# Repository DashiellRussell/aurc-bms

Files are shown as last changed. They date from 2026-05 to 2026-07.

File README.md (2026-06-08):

# AURC_BMS

Battery Management System for AURC (Australian Universities Rocket Competition).
Four-channel battery board set feeding two flight computers (FC1, FC2) and two pyro boards.
KiCad 10 project set.

## Layout

```
AURC_BMS/
├── libs/                     ← shared, single source of truth (all three boards point here)
│   ├── BMS.kicad_sym         ← symbols
│   ├── BMS.pretty/           ← footprints
│   └── 3dmodels/             ← .step / .wrl
├── docs/
│   ├── interconnect.md                ← the connector contract — READ THIS before touching a board edge
│   ├── architecture.md                ← full design rationale (living doc, currently v0.3)
│   └── board1_power_capture_plan.md   ← Board 1 schematic capture plan (sheets, netlist, BOM)
├── board1_power/             ← Board 1: USB-C, PD sink, 4× SY6970 smart charger, cells, ESP+I²C mux
├── board2_monitor/           ← Board 2: 64-LED gauge + driver, 4× pull-pin power-enable (spine)
├── board3_dist/              ← Board 3: passive fan-out to FC1+Pyro1 / FC2+Pyro2
└── _archive/                 ← previous single-board attempt (v0.1), kept for reference
```

Each `boardN_*/` is an independent KiCad project (`.kicad_pro` / `.kicad_sch` / `.kicad_pcb`) with
its own `sym-lib-table` + `fp-lib-table` that resolve the **shared** library at `../libs/` under
the nickname **`BMS`**. Add a part once in `libs/`; all three boards see it.

## Working on it

- **Before changing any board-to-board connector, edit `docs/interconnect.md` first.** It is the
  only thing keeping the three separately-laid-out boards mate-compatible.
- Add/edit symbols in `libs/BMS.kicad_sym`, footprints in `libs/BMS.pretty/`, 3D models in
  `libs/3dmodels/`. Don't make per-board copies — that defeats the single-source-of-truth setup.
- Open a board by opening its `boardN_*/boardN_*.kicad_pro`.

See `docs/architecture.md` for the full design (protection stack, charging, monitoring,
power-enable/safety, BOM, open items).

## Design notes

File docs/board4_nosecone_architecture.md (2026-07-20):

# AURC Nosecone BMS (board4) — Architecture & Design

**Version:** 0.1
**Scope:** Two-channel, single-board battery board feeding two FC/logic loads in the nosecone.
**Parent design:** `architecture.md` v0.5 (the 4-channel board1–3 set). This board inherits every
decision from that document unless a section below explicitly overrides it. Read that for *why*;
read this for *what changed*.
**Status:** Pre-schematic. Open items in §9.

---

## 1. What this board is

The nosecone carries its own avionics, powered by **two independent 1S 18650 channels**, both
feeding **flight-computer / logic loads** (no pyro). Unlike the main bay's 3-board stack, nosecone
volume dictates a **single PCB**: charger, cells, protection, pull-pin power-enable, monitoring,
and load distribution all on `board4_nosecone`. Rectangular sled mount (dimensions TBD, §9.1).

**Deltas from the 4-channel set, at a glance:**

| | board1–3 set | board4 nosecone |
|---|---|---|
| Channels | 4 (FC1, FC2, Pyro1, Pyro2) | **2 (NFC1, NFC2 — both FC/logic)** |
| Boards | 3-board mezzanine stack | **single board** |
| Pyro path | low-Rds FETs, firing-pulse PTC sizing | **none — no firing pulses anywhere** |
| I²C to chargers | TCA9548A mux (4× SY6970 @ 0x6B) | **no mux — one SY6970 per ESP32-S3 I²C controller** |
| Gauge | Board-2 64-LED IS31FL3731 matrix | **dropped — SK6812 RGB + /STAT LEDs only** |
| WAKE button | on Board 2, via J1s | **on-board tactile switch** |
| PD request | 12 V (30 W budget) | **9 V default (≈15 W budget), 12 V strap option** |

---

## 2. Channel model

- **Two electrically independent 1S channels**: `NCH1_V` → NFC1, `NCH2_V` → NFC2. Independent
  positive rails; returns star-bonded at **one point on this board, next to the cells** (per-channel
  ground-to-star `0Ω` links, R 0603 — same convention as §12 of the parent doc).
- No series stack → no balancing. No pyro → **no low-Rds exception, no firing-pulse arithmetic** —
  the DW01A + SI4920DY stack and PTC are sized purely for FC continuous draw + inrush (§9.2).
- Net names: `NCH{1,2}_V`, `NCH{1,2}_V_SW` (downstream of pull pin), `NCH{1,2}_GND`. The `N` prefix
  keeps nosecone nets grep-distinct from the main set's `CH{1..4}_*`.

## 3. Per-cell protection stack (per channel, cell outward)

Identical philosophy and parts to parent §4, minus the pyro clauses:

1. **Reverse-polarity P-FET at the cell terminal** — DMG2305UX (or AO3401A as drawn in `BMS` lib),
   SOT-23. Keyed holder remains the primary defense; compensate Rds drop via the I²C VREG trim.
2. **DW01A + SI4920DY** in the cell-negative path (`Battery_Management:DW01A`, `BMS:SI4920DY`) —
   over-charge/over-discharge/OC. No lower-Rds substitution needed.
3. **SY6970** power-path charger — same silicon rules as parent §5 (VSYSMIN 3.5 V, BATFET default-on,
   **no ship mode in flight**, `/QON` strapped high). Cap set per parent: bootstrap **47 nF (C 0603)**,
   PMID **6.8 µF (C 0805)**, BAT ≥10 µF (C 0805), SYS ≥10 µF (C 0805), REGN 4.7 µF (C 0603),
   inductor SRP5030CA-2R2M 2.2 µH.
4. **`SYS` / `LOAD_P` source-select 0Ω strap (R 0603)** then **resettable PTC** on each `NCHn_V`
   output. PTC hold/trip sized to the actual nosecone FC draw — **open item §9.2** (no 2 A pulse to
   pass this time, so it can trip much lower than the main board's).

NTC on each SY6970 TS pin (10 k NTC 0603 + bias per datasheet) for the 0–45 °C charge window.

## 4. Charging & USB-C

Parent §5 applies wholesale (single dual-purpose USB-C: PD sink + ESP native USB, USBLC6-2SC6 ESD,
CH224K strap-select). Changes:

- **Budget:** 2 cells × 1.5 A ≈ 12.6 W at the cells ≈ 15 W input → **request 9 V** (a 9 V/2 A phone
  brick suffices); keep the 12 V strap position for sharing the main board's brick.
- Charge current still I²C-programmed (~1.0–1.5 A/cell); ILIM resistor per datasheet.

## 5. I²C topology — mux deleted

Both SY6970s are fixed at 0x6B, but the **ESP32-S3 has two hardware I²C controllers** — so instead
of a TCA9548A:

- **I2C0:** SDA0/SCL0 → SY6970 #1 (NCH1)
- **I2C1:** SDA1/SCL1 → SY6970 #2 (NCH2)
- 4.7 k pull-ups (R 0603) on **each** bus, to the ESP 3V3 rail.

Nothing else shares the buses (no gauge driver on this board). Two parts and a RST line deleted
relative to board1.

## 6. ESP, monitoring & indicators

**ESP32-S3-WROOM-1** on NCH1, same power-gating as parent §7 (as-built board1 scheme):
`NCH1_V → AP2112K-3.3`, EN driven by the MMBD4448HCQW diode-OR of {USB divider, always-on 100 k
strap (R 0603), WAKE, self-hold GPIO}, 100 k pull-down (R 0603), 2N7002 RBF off-jumper shunt.
BLE stream stays **read-only, forever**.

- **WAKE is now an on-board tactile switch** (`NCH1_V` → WAKE through the button), since there is
  no Board 2. Same debounce/limiting as the board1 J1s arrangement.
- **Hardwired LEDs (always fitted, ESP-independent):** per-channel SY6970 /STAT LED (2×, LED 0603 +
  R 0603), USB-present LED, fault LED — the dumb fallback, as parent §9a.
- **Rich status LEDs — DECIDED: (a) 2× SK6812** (ease of use; everything stays ESP-controlled over
  one GPIO). Options considered for the record:
  - **(a) 2× SK6812 RGB**, daisy-chained on one GPIO (parent §9b scheme). Fewest parts, colour
    encodes state, no charge-*level* bar. VDD from `NCH1_V` (same storage-drain caveat — pull cells
    for storage or gate the rail).
  - **(b) IS31FL3731 charlieplex driver** (I²C 0x74, shares a bus with one charger, no address
    clash) + a small LED bar — e.g. 8 LEDs/cell charge bar + 2 diagnostics, ~20 LEDs of the 144 the
    matrix supports, no per-LED resistors, hardware breathe engine. This is Board 2's gauge scaled
    down and pulled on-board; symbol already in the libs.
  - **(c) Raw ESP-GPIO charlieplexing** — no driver IC, but N(N−1) LEDs costs N GPIOs *and*
    firmware scan timing, and the LEDs die the instant the ESP sleeps. Worst of both; avoid.
  - **Recommendation: (a), plus (b) only if a visible charge-level bar on the sled is genuinely
    wanted** — in the nosecone the board is buried at integration, and BLE already gives exact
    numbers on a phone, which weakens the case for a bar this time.
- SoC-by-voltage over BLE via the two chargers' internal ADCs, exactly as the main board.

## 7. Power-enable & outputs

- **2× pull-pin power-enable on a single 4-position screw terminal block** (1×4, one pin pair per
  channel: positions 1–2 = NCH1 loop, 3–4 = NCH2 loop), both **FC-keyed** — no pyro keying needed
  on this board. Pin inserted = isolated; removed = live (captive pins, parent §8). One block
  instead of the main set's four separate 2-pin terminals; silkscreen the two loops clearly since
  the block itself gives no keying.
- Because the pull-pin switch and distribution are on-board, `NCHn_V → strap/PTC → pull-pin →
  NCHn_V_SW → output connector` is one board's routing — no interconnect contract needed beyond:

**J1 — nosecone loads (4-pin, 3 A/pin):**

| Pin | Net |
|---|---|
| 1 | NFC1_V (= NCH1_V_SW) |
| 2 | NFC1_GND (= NCH1_GND) |
| 3 | NFC2_V (= NCH2_V_SW) |
| 4 | NFC2_GND (= NCH2_GND) |

Per-channel V and GND kept separate end-to-end; grounds meet only at the on-board star point.

## 8. BOM deltas vs parent §11

All quantities ×2 instead of ×4 (SY6970QCC, SRP5030CA-2R2M, DW01A+SI4920DY, reverse P-FET, PTC,
NTC, SK6812). Passives R/C **0603** throughout unless a section above says otherwise.

| Change | Part |
|---|---|
| **Deleted** | TCA9548A mux; IS31FL3731 + 64-LED matrix; mezzanine connectors; gauge-button wiring across J1s |
| **Added** | on-board tactile WAKE switch (6×6 mm THT or SMD tact); 1×4 screw terminal block (pull-pin loops, replaces 4× 2-pin terminals) |
| Unchanged | CH224K, ESP32-S3-WROOM-1, AP2112K-3.3, USBLC6-2SC6, MMBD4448HCQW, 2N7002 |

## 9. Open items

1. **Sled dimensions + mounting-hole pattern** — outline TBD; design proceeds electrically first.
2. **Nosecone FC current draw** → PTC hold/trip rating and DW01A OC sanity check.
3. **What exactly are the two loads?** (Two redundant FCs? FC + tracker?) — affects nothing
   electrical so far, but name the connector pins properly once known.
4. **18650 holder orientation on the sled** — axial G-loading on holders; confirm retention.
5. Confirm nosecone is RF-transparent for BLE (fibreglass tip likely fine; carbon is not).
6. **Rich status-LED scheme** — SK6812 vs on-board IS31FL3731 charlieplex bar (§6). Recommendation
   is SK6812-only; decide before capture since it changes the I²C bus loading and LED area.

## 10. Revision history

| Version | Notes |
|---|---|
| 0.1 | Initial: 2-channel FC/logic-only derivative of architecture.md v0.5 on a single sled-mounted board. Mux dropped (dual ESP I²C buses), gauge dropped (SK6812 + /STAT only), WAKE button moved on-board, PD request 9 V default. |

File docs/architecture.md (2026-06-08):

# AURC Avionics BMS — Architecture & Design

**Version:** 0.3 (parts re-confirmed against existing capture; Board 1 plan in `board1_power_capture_plan.md`)
**Scope:** Four-channel battery board set feeding two flight computers (FC1 primary, FC2 backup) and two pyrotechnic boards, for AURC.
**Status:** Board 1 schematic capture in progress. Remaining open items in §13.

> **v0.3 change (2026-06-08):** charger/monitoring topology switched from *MP2617 + MAX17048* to the
> **SY6970** smart charger already drawn in the existing capture. The SY6970 (BQ25896-class) does
> power-path charging **and** integrated I²C V/I/charge monitoring in one IC, so the separate
> MAX17048 fuel gauge is dropped. The TCA9548A mux stays (4× SY6970 share addr 0x6B). ESP confirmed
> as **ESP32-S3-WROOM-1**. Tradeoff: ADC-grade monitoring instead of true coulomb-counting SoC —
> accepted for the lower part count. See §5, §6, §11.

---

## 1. Design philosophy

- **Four electrically independent 1S channels.** One 18650 per channel: FC1, FC2, Pyro1, Pyro2. Independent positive rails; returns joined at a single star point. No series stack → **no cell balancing**.
- **The monitoring layer is non-flight-critical.** The ESP, LED gauge, and BLE telemetry sit entirely outside the flight power path. Fallback is always "fit a charged cell and fly." Nothing in the flight or deployment path may depend on the ESP — hard rule.
- **No on-board arming, no pyro circuitry.** This board does not arm or fire anything. The pull pins are per-channel **power-enable / battery isolation** only. All pyro firing (e-match, firing FET, opto, continuity) lives on the pyro boards downstream; the BMS only delivers power to their inputs.
- **Remove-before-flight power enable.** Pull pin inserted = channel isolated (safe to handle). Pull pin removed = channel power flows.
- **Three boards.** Board 1 (power/charge) and Board 2 (monitor) are active; Board 3 (distribution) is passive.

---

## 2. System architecture

| Board | Role | Key contents |
|---|---|---|
| 1 — Power & charge | active | USB-C (charge + ESP programming), PD sink, 4× SY6970 smart chargers (charge + integrated I²C monitoring), 4× 18650 holders, per-cell protection, I2C mux, ESP module, indicator LEDs |
| 2 — Safe & monitor | active | 64-LED gauge + IS31FL3731 driver, gauge button; pull-pin power-enable interface at the 2→3 edge |
| 3 — Distribution | passive | fan-out to FC1+Pyro1 (Conn A) and FC2+Pyro2 (Conn B) |

**Mechanical (to confirm):** Boards 1 and 3 stack parallel; Board 2 is the spine/interconnect carrying the gauge and the pull-pin interface. Board-to-board via **stacking mezzanine connectors**.

**Inter-board connectors**

- **Board 1 ↔ 2:** 8-pin power (4× V + 4× GND, 3 A/pin) + 4-pin signal (I2C to gauge driver, plus channel-live sense + GND).
- **Board 2 ↔ 3:** 8-pin power (4× V + 4× GND, 3 A/pin) routed through the pull-pin power-enable interface.
- **Board 3 → loads:** Conn A (FC1 V/GND + Pyro1 V/GND), Conn B (FC2 V/GND + Pyro2 V/GND). Per-channel V and GND kept separate.

---

## 3. Channel & independence model

- Four independent positive rails; a fault on one channel cannot pull down another's supply.
- Grounds meet at a **single star point** (location TBD, likely Board 1 by the cells), not a shared plane — independent returns, OZONE PYRO_GND philosophy.
- One USB-C port references the four chargers to a common input ground during charging; acceptable because flight returns are independent and star-bonded at one point. No galvanic isolation.

---

## 4. Per-cell protection stack

In series order from the cell outward:

1. **Reverse-polarity P-FET — at the cell terminal, ahead of the charger tap.** Low-Rds P-FET (DMG2305UX / SI2333-class) so a backwards cell can't reach the SY6970 BAT pin. **Always in circuit, independent of the §5 source select.** It carries full charge + firing-pulse current, so compensate its Rds drop by trimming the I²C charge voltage up by `I_CHG·R_DS`. The **keyed holder is the primary defense**; this FET is the electrical backstop that also guards the charger. *(The SY6970 has its own internal input reverse-blocking FET — 25 mΩ — but that protects the USB side, not against a backwards cell.)*
2. **Protection IC** — DW01A + SI4920DY dual N-FET, in the cell-negative path: over-charge (~4.3 V), over-discharge (~2.4 V), fast electronic over-current/short.
3. **Power-path charger (SY6970)** — switching power-path; see §5. Brings its own layers: **9 A BATFET discharge OCP, 104 % battery OVP, input/system OVP, 160 °C thermal shutdown** (datasheet-verified).
4. **Source select + fuse — on the `CHn_V` output.** A `0Ω` strap picks the channel's output source: **`SYS` (charger power-path, default)** or **`LOAD_P` (direct protected battery)** — see §5/§12. A single resettable **PTC sits after the selector**, fusing the output whichever source is chosen: the slow catastrophic-short backstop for the "silicon failed shorted" case, sized to pass the brief 2 A firing pulse and trip on a sustained short.

**Pyro-channel exception:** the firing-pulse return flows through the DW01A/SI4920DY FETs, so the over-current trip must sit **above** firing inrush. Trip ≈ `V_OV(DW01A ~100–150 mV) ÷ (2·R_DS(SI4920DY))` — verify R_DS keeps this ≳1.5× the 2 A pulse; drop to a lower-Rds FET on the pyro channels if not (§13.4). The pyro cell barely cycles (a few mAh/shot), so over-discharge risk is low.

**Charge temperature cutoff:** NTC on each charger's TS pin to inhibit charging outside ~0–45 °C.

**Over-charge:** doubly covered — DW01A over-charge **and** the SY6970's 104 % VBATOVP.

---

## 5. Charging & USB-C

**Single USB-C port, dual purpose:** PD charging (VBUS + CC) and ESP programming (D+/D- to the S3 module's native USB). Separate pins, no conflict.

- **PD sink** requests 9–12 V (strap-selectable), falls back to 5 V on a non-PD host, so a PC port is never overvolted.
- **4× SY6970 power-path chargers** (Silergy, BQ25896-class), one per cell. ~3.9–14 V input covers both a 5 V PC port and a 9–12 V brick. Switching buck power-path (system/load served first), I²C-programmable input current limit + charge current, TS temperature pin, /STAT + /INT indicators, integrated 16-bit ADC. No external charge-current sense resistor.
- **Switching, not linear** — each charger bucks 12 V → 4.2 V efficiently; no front-end converter needed. Each needs its own inductor (SRP5030CA-2R2M) + input/output caps.
- **Charge current is set over I²C** (CICHG register), not a resistor strap — so it can be tuned in firmware per source. Target ~1.0–1.5 A/cell: 1.0 A fits a 9 V/2 A phone charger (~3 h); 1.5 A (≈0.5 C) wants a 12 V/3 A brick (~2 h). Input-current limit (ILIM pin resistor + I²C DPM) throttles on a weak source.
- **Monitoring comes free:** the same SY6970 reports VBUS/VBAT/VSYS/ICHG/IBUS/TS over I²C — see §6. This is why no separate fuel gauge is fitted.
- **Flight rail = SYS by default.** Each channel's J1 output (`CHn_V`) is picked by a `0Ω` strap: **`SYS`** (charger power-path — default; runs the load from USB while charging, spares the cell) or **`LOAD_P`** (direct protected battery). One PTC after the selector fuses either (§4). Free per-channel choice (e.g. SYS on the FCs, LOAD_P on the pyros) just by which 0Ω is stuffed.
- **Verified SY6970 silicon** (datasheet): VSYSMIN **3.5 V** (3.65 typ), SYS ≈ VBAT+50 mV with a battery present; **BATFET 10 mΩ / 9 A discharge OCP** → a 2 A pyro pulse is trivial; **supplement mode** lets the cell back up the input on load spikes.
- **Reliability rule — never enter ship mode in flight.** BATFET defaults on and the I²C watchdog resets *to* BATFET-on, so SYS survives a dead ESP; but an I²C BATFET-disable (or a 10 s `/QON`-low hold) drops the rail. Strap `/QON` high (no button) and bar firmware from disabling the BATFET on flight channels.
- **Cap corrections** (datasheet typical-app): bootstrap **47 nF** (not 47 µF), **PMID 6.8 µF**, BAT ≥10 µF, SYS ≥10 µF, REGN 4.7 µF.

**ESP programming:** D+/D- straight to the ESP32-S3 module (native USB-Serial-JTAG, no UART bridge). USBLC6-class ESD on D+/D-, BOOT/EN pads. The flight computers are **not** programmed here (their own SWD); the USB bypass only *powers* them for bench debug.

**Power budget:** four cells at 1.5 A ≈ 25 W at the cells ≈ 28 W input, plus ~2 W bypass ≈ 30 W → request 12 V (36 W) for margin.

---

## 6. Sensing & monitoring

- **Monitoring is built into the SY6970 chargers** — each integrates a 16-bit ADC reporting VBAT, VSYS, VBUS, ICHG, IBUS and TS over I²C. No separate fuel gauge or sense resistor is added to the firing path. Tradeoff vs. a dedicated ModelGauge (MAX17048): this is **ADC/voltage-based** state, not true coulomb-counting SoC — accepted for the lower part count; firmware estimates SoC from voltage + charge state + the TS-derived temperature.
- The SY6970 has a **fixed I²C address (0x6B)**, so the four sit behind a **TCA9548A 8-channel I²C mux** (one channel each). Total ESP pins for all monitoring: 2 (SDA/SCL).
- I²C bus topology: ESP → TCA9548A (4× SY6970 chargers, Board 1) and, **upstream of the mux**, across the 4-pin connector → IS31FL3731 gauge driver (Board 2, addr 0x74, no conflict). Pull-ups (4.7 k) on Board 1. The mux RST line (`MUX_RST`) is driven by the ESP.
- Per-cell temperature comes from each SY6970's TS NTC, read back over the same I²C ADC.

---

## 7. ESP, gauge & telemetry

**ESP32-S3-WROOM-1 module** on cell 1 (FC1 channel), behind its own load switch (TPS22917-class) + fuse so a fault can't drag down FC1.
- Reads four SY6970 chargers (V/I/charge/temperature) over the muxed I²C bus.
- Drives the gauge over I2C.
- Streams charge + channel-live state over BLE — **read-only, forever**; never accepts a command.
- Supply regulated to 3.3 V from SYS/charge rail — **never raw VBUS**.

**ESP power gating (as built):** the AP2112K `EN` is driven by a **diode-OR** (`MMBD4448HCQW`, quad common-cathode) of four sources, with a 100 k pull-down → **default off**:
- **USB present** → VBUS 100 k/33 k divider pulls `EN` high (gauge shows charging).
- **Always-on strap** (`R59`, 100 k from `CH1_V`) → sustained-on for flight BLE.
- **Gauge button → `WAKE`** (across the J1↔J2 signal connector, §interconnect) → momentary wake; the ESP then drives its **self-hold** GPIO into the diode-OR to latch on, paints the gauge N s, then releases → powers down.
- **ESP self-hold** GPIO → holds itself on; the **watchdog** drops it on a firmware hang (can't strand it on).
- **Off header (RBF jumper)** — a `2N7002` **shunt** on `EN` (drain→EN, source→GND), gate fed from `CH1_V` through the launch-day jumper `J4`: **jumper in → `EN`→GND → ESP off** (integration/storage week); **removed on launch day → ESP on**. Overrides all four sources (which are current-limited).
- Supply: `CH1_V → AP2112K → 3.3 V`; **never raw VBUS** (VBUS only reaches `EN` through the divider).

*(This replaces the earlier "dedicated TPS22917 load switch" plan — the AP2112K `EN` is the gate; a load switch was deemed redundant for gating only the ESP rail.)*

**Gauge:** 64 LEDs via **IS31FL3731 (eTQFP-28)**, per-LED PWM, hardware breathe/animation engine. Per channel: a charge-level bar plus **2 diagnostic LEDs** (over-temp warning, fault/protection-tripped). Charlieplex matrix — wire the four channels as contiguous blocks. No per-LED resistors. Powered from the charge rail (dead in flight). AD strap = 0x74, SDB to enable/GPIO.

---

## 8. Power-enable (pull pins) & safety

- **Remove-before-flight power enable.** Pin inserted = channel isolated; removed = power flows. *Default-unpinned is live* — use captive/retained pins.
- **Four independent pull pins**, one per channel (4× 2-pin screw terminal), enabling sequenced power-up: bring up FC channels first for checks, pyro channels last.
- **Key/colour the pyro pins** distinctly from the FC pins.
- **Firing-FET-held-off** is a downstream pyro-board requirement, out of BMS scope — but the BMS must deliver clean, transient-free power so applying power can't glitch a load.
- **Hot-plug inrush:** size input caps + soft-start.

---

## 9. Indicator LEDs

Two tiers, so the board is never silent regardless of ESP firmware state.

**9a. Hardwired (ESP-independent) — the dumb fallback**
- Per-channel charge status (4×) from each SY6970 /STAT pin (on = charging, off = done, blink = fault).
- USB / input-present.
- Fault (e.g., protection or charger fault).

These give basic board state even with the ESP off or firmware dead.

**9b. Per-cell RGB status (ESP-driven) — the rich indicator**
- **One addressable RGB LED per cell (SK6812 / WS2812B), 4× total, daisy-chained on a single ESP
  GPIO** (DIN→DOUT through all four). The ESP already reads each SY6970's V/I/charge/fault/temp over
  I²C, so it has everything needed to paint exact per-cell state — visible on Board 1 alone, **no
  Board 2 required**. Because USB-present ⇒ ESP-on, these are live whenever anything is charging.
- Colour scheme (mirrors the Board-2 gauge diagnostics): **green breathing = charging · solid blue =
  charged · red = fault/protection · amber = over-temp · off = idle/no cell.**
- **LED VDD is on `CH1_V`** (the always-live cell rail, *not* the 3V3 LDO) — **note:** ungated, so the SK6812 idle (~2–4 mA total) drains cell 1 during a cells-in storage week; gate the LED rail (or store cells out) if that matters. Original sizing note: (4× WS2812 ≈ 240 mA at full white;
  the AP2112K can't source that). Only the data line touches the ESP — level-shift it (use SK6812
  for 3.3 V tolerance, or a 74AHCT125 / SN74LVC2T45). Dead in flight, like all monitoring.

---

## 10. Operational states

| State | USB | FC pins | Pyro pins | ESP / BLE | Gauge | Loads |
|---|---|---|---|---|---|---|
| Storage (days out) | out | in (isolated) | in (isolated) | off — jumper in | off | off |
| Charging | in | in | in | on, charge rail | levels | off |
| Bench / FC debug | in | out | in | on / momentary | readout | FCs live, pyro isolated |
| Pad power-up | out | out | out (last) | on, BLE — jumper out | off | live |
| Flight / recovery | out | out | out | sleeps on link loss | off | live |

Invariants: chargers inherently dead without USB; per-cell protection always live (µA); gauge never auto-powers off the cells; ESP rail hard-cut by a load switch.

---

## 11. Candidate BOM (verify current LCSC stock + package)

| Function | Candidate | Notes |
|---|---|---|
| Charger + monitor ×4 | **SY6970QCC** | BQ25896-class, ~3.9–14 V in, switching power-path, I²C 0x6B, integrated ADC (V/I/charge/TS), /STAT + /INT. Replaces the MP2617 **and** the fuel gauge. In `libs/BMS.kicad_sym`. |
| Charger inductor ×4 | SRP5030CA-2R2M | 2.2 µH, for the SY6970 buck. In `libs/BMS.kicad_sym`. |
| Protection ×4 | DW01A + SI4920DY dual N-FET | `Battery_Management:DW01A` + `libs/BMS:SI4920DY`. Use a lower-Rds FET on the pyro channels. |
| Reverse-polarity ×4 | AO3401A P-FET (existing) — consider DMG2305UX / SI2333 for lower Rds | `Transistor_FET:AO3401A` |
| Fuse/PTC ×4 | resettable PTC | rated above firing pulse, below sustained short |
| ~~Fuel gauge~~ | **dropped** | monitoring folded into the SY6970 (see §6) |
| I2C mux | TCA9548A | `Interface_Expansion:TCA9548APWR`; hosts the four 0x6B SY6970s |
| PD sink | CH224K (or STUSB4500) | resistor-strap voltage select. In `libs/BMS.kicad_sym`. |
| Gauge driver (Board 2) | IS31FL3731 | eTQFP-28, I²C 0x74, 64 LEDs |
| ESP | ESP32-S3-WROOM-1 | `RF_Module:ESP32-S3-WROOM-1` |
| ESP load switch | TPS22917-class | `Power_Switch` — hard-gates the ESP rail |
| Per-cell RGB status ×4 | SK6812 / WS2812B | addressable, daisy-chained on 1 ESP GPIO; VDD from SYS rail (§9b) |
| LED data level shift | SK6812 (3.3 V tolerant) or 74AHCT125 / SN74LVC2T45 | only if WS2812B used |
| 3V3 LDO | AP2112K-3.3 | `Regulator_Linear:AP2112K-3.3` |
| ESD | USBLC6-2SC6 | `Power_Protection:USBLC6-2SC6`, on D+/D- |

---

## 12. Configuration straps (0Ω / populate)

ESP source select (charge-rail vs cell-1) + always-on capability strap · PD voltage request (9/12/15 V) · ~~per-cell charge-current set~~ *(now I²C-programmed on the SY6970 — only the ILIM input-current resistor remains)* · D+/D- series 0Ω · PD-sink bypass (force 5 V) · per-channel ground-to-star 0Ω · per-channel enable source (pin vs always-on for bench) · **per-channel `CHn_V` source select — `0R_SYS` (default) vs `0R_LOAD`** (SYS power-path vs direct battery, §4/§5).

---

## 13. Open items

1. **Mechanical stack confirmation** — Boards 1 & 3 parallel, Board 2 spine, mezzanine connectors? Confirm mezzanine part/pitch.
2. **Channel-live sense granularity** — combined (1 line, keeps the 4-pin connector) vs per-channel (4 lines, larger connector or local read on Board 2). Needed if the gauge/BLE should show each channel.
3. **Star-point location** — fix it in copper.
4. **Pyro OC trip numbers** — verify firing inrush vs the chosen FS8205 Rds and the PTC rating against the specific e-match.
5. **Project name.**

---

## 14. Revision history

| Version | Notes |
|---|---|
| 0.1 | Initial architecture: 3-board set, 4 independent 1S channels, RBF pull pins, power-path PD charging, dual-purpose USB-C, per-cell protection, non-flight-critical monitoring layer. |
| 0.2 | Parts selected (MP2617 charger, MAX17048 + TCA9548A mux, CH224K PD sink, DW01A+FS8205 protection, IS31FL3731 gauge, ESP32-S3-WROOM-1, P30B 18650 cell). Corrected terminology: no on-board arming — pull pins are power-enable/isolation. Added fuel-gauge sensing, hardwired indicator LEDs, mechanical stack note (Boards 1+3 stacked, Board 2 spine), candidate BOM. |
| 0.3 | **Charger/monitoring topology revised to match existing capture:** SY6970 smart charger (charge + integrated I²C monitoring) replaces MP2617 + MAX17048; separate fuel gauge dropped; TCA9548A mux retained (4× shared 0x6B). ESP confirmed ESP32-S3-WROOM-1. BOM rows mapped to concrete KiCad/`BMS` symbol libraries. Added ESP load-switch (TPS22917) + 3V3 LDO (AP2112K) to BOM. Charge current moved from resistor strap to I²C register. Board 1 capture plan written (`board1_power_capture_plan.md`). Added **per-cell addressable RGB status LEDs** (§9b) on Board 1 — ESP-driven, standalone of Board 2. |
| 0.4 | **Channel output finalized.** Per-channel `CHn_V` is source-selectable by 0Ω — **SYS (default)** or LOAD_P (direct battery); one PTC relocated *after* the selector to fuse either. **Reverse-polarity P-FET moved to the cell terminal** (always-on, now actually guards the charger; Rds drop compensated via I²C VREG); old Q2/Q3 LOAD-branch FETs dropped, keyed holder = primary reverse defense. SY6970 datasheet-verified (VSYSMIN 3.5 V, BATFET 10 mΩ / 9 A OCP, 104 % OVP, supplement mode). Bootstrap cap corrected 47 µF→47 nF, PMID→6.8 µF. Added "no ship-mode in flight" reliability rule. |
| 0.5 | **Board 1 schematic complete (as-built sync).** ESP gate = diode-OR (`MMBD4448HCQW`) of {USB-divider, `CH1_V` always-on strap, `WAKE`, self-hold} → AP2112K `EN`, 100 k pull-down, `2N7002` off-header shunt (RBF: jumper in = off, out = on) — *replaces the TPS22917 load-switch plan*. `CH_LIVE` repurposed to **`WAKE`** on the J1s signal connector (channel-live now derived in firmware via SY6970 I²C / BLE). Board-2 gauge powered from `CH1_V` via the 8-pin power connector (no 3V3 pass-through). All footprints assigned (R/C 0603). Pyro OC-trip verified safe (DW01A ~10 ms delay ≫ <5 ms firing pulse). |

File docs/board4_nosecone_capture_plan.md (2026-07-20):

# Board 4 — Nosecone BMS — Schematic Capture Plan

Capture plan for `board4_nosecone/board4_nosecone.kicad_sch`. Authority order:
`board4_nosecone_architecture.md` (this board's deltas) → `architecture.md` v0.5 (inherited design)
→ this file (capture detail). Where this plan and board1's plan disagree, follow this one —
board1's plan (`board1_power_capture_plan.md`) predates the as-built v0.5 ESP gating.

**Locked decisions (2026-07-20):** single board · 2× FC/logic channels (no pyro) · 2× SY6970, one
per ESP32-S3 I²C controller (**no TCA9548A**) · **2× SK6812** ESP-driven status RGBs + hardwired
/STAT-fallback LEDs (**no IS31FL3731**) · on-board WAKE tact switch · 1×4 screw terminal for both
pull-pin loops · PD request 9 V default · rectangular sled (dims TBD).

> **Head start (already done):** `charge_chanel.kicad_sch` and `USB_IN.kicad_sch` are **copied from
> board1 as-built** into `board4_nosecone/` — both proven sheets, lib refs identical (`BMS:` via the
> project lib tables). The ESP/monitor section is the only fresh drawing, and it's *simpler* than
> board1's (mux deleted).

---

## 1. Sheet hierarchy

```
board4_nosecone.kicad_sch  (ROOT — ESP section drawn here, board1-style)
├── USB_IN.kicad_sch          ×1   USB-C + CH224K + ESD    ← copied, edit strap only
└── charge_chanel.kicad_sch   ×2   SY6970 + protection + 18650 + SK6812   ← copied, use as-is
ROOT also holds: ESP32-S3 + AP2112K + diode-OR gate, WAKE button, J1 out, 1×4 pull-pin block,
star ground, hardwired LEDs.
```

Instantiate **one** `charge_chanel` sheet file twice (NCH1, NCH2). Differences are wired at root
via sheet pins, exactly like board1.

## 2. Global nets (N-prefixed per architecture §2)

| Net | Meaning |
|---|---|
| `VBUS` | PD rail (**9 V** default) |
| `NCH1_V`, `NCH2_V` | per-channel SYS rail (charger out, post-strap/PTC) |
| `NCH1_V_SW`, `NCH2_V_SW` | downstream of pull-pin loop → J1 |
| `NCH1_GND`, `NCH2_GND` | independent returns → single on-board star by the cells |
| `SDA0/SCL0`, `SDA1/SCL1` | ESP I2C0 → SY6970 #1, I2C1 → SY6970 #2 (4.7 k pull-ups to `+3V3` on **each** bus, R 0603) |
| `USB_DP/USB_DM` | native USB to the S3 |
| `+3V3` | AP2112K output |
| `WAKE` | tact switch: `NCH1_V` → button → diode-OR input |
| `STAT1/STAT2` | /STAT → hardwired fallback LEDs |
| `RGB_DATA` → DIN/DOUT chain | 2× SK6812, `LED_VDD` = `NCH1_V` |

## 3. Per-sheet work

**`USB_IN` (copied):** only change — **CH224K strapped to 9 V**. Per datasheet, 9 V = CFG1 = CFG2 =
CFG3 all LOW (GND). As copied from board1: CFG1 already has a 24 K to GND (= logic 0, good), but
**CFG2 and CFG3 are floating** — add a **0 Ω (`R_0603_1608Metric`) from each of CFG2 and CFG3 to
GND**. No 12 V DNP position kept: CFG2/CFG3 cap at 3.7 V so a clean 12 V strap (CFG3 = 1) needs a
≤3.7 V pull-up rail — treat 12 V as a rework if ever needed. Everything else (USBLC6, bulk cap,
input LED) stays.

**`charge_chanel` ×2 (copied):** use as-is. The copied sheet already carries SY6970 + DW01A +
SI4920DY + AO3401A + SRP5030 + PTC + NTC + /STAT + SK6812 with the right cap set (47 nF bootstrap,
6.8 µF PMID, etc.). Per-instance wiring at root: instance 1 gets `SDA0/SCL0`, instance 2 gets
`SDA1/SCL1`. **PTC value may change** vs board1 (no firing pulse — size to FC draw, open item).

**ROOT / ESP section (fresh, ~board1's root minus the mux):**
- `NCH1_V → AP2112K-3.3 → +3V3`. EN = diode-OR (`MMBD4448HCQW`) of {VBUS 100k/33k divider,
  always-on 100 k strap from `NCH1_V`, `WAKE`, ESP self-hold GPIO}, 100 k pull-down, `2N7002`
  RBF-jumper shunt on EN (jumper in = ESP off). All R 0603. Copy this block from board1's root —
  it is the as-built v0.5 circuit.
- ESP32-S3-WROOM-1: `USB_D±` ← `USB_DP/DM`; **two GPIO pairs → `SDA0/SCL0` and `SDA1/SCL1`**
  (any GPIOs — the S3's two I²C controllers route via the GPIO matrix); one GPIO → `RGB_DATA`
  (330 Ω series, R 0603); one GPIO → self-hold into the diode-OR; EN RC + BOOT pad per board1.
- **WAKE tact switch** (6×6 mm): `NCH1_V` → switch → `WAKE` net (through the same limiting as
  board1's J1s arrangement).
- **Firmware note:** advertise as a distinct BLE name (`AURC-BMS-NOSE` vs the main board's
  `AURC-BMS-MAIN`) so the Web Bluetooth page can tell the two boards apart. No RF coexistence
  concern — BLE AFH handles two radios 50 cm apart trivially.

**ROOT / power-out section:**
- Each `NCHn_V` → **1×4 screw terminal** (pull-pin loop: pins 1–2 = NCH1, 3–4 = NCH2) → `NCHn_V_SW`.
- **J1 — loads, 4-pin, 3 A/pin:** 1 `NFC1_V`(=NCH1_V_SW) · 2 `NFC1_GND` · 3 `NFC2_V`(=NCH2_V_SW) ·
  4 `NFC2_GND`.
- **Star ground by the cells:** `NCH1_GND` + `NCH2_GND` + USB GND + signal ground join at exactly
  one node via per-channel 0Ω links (R 0603). No shared plane across channels.

## 4. Config straps (0Ω / DNP, all R 0603)

PD voltage 9 V (default) / 12 V · PD bypass (force 5 V) · D+/D− series 0Ω ×2 · ESP always-on strap ·
per-channel `SYS` vs `LOAD_P` source select ×2 · per-channel ground-to-star ×2 · SY6970 ILIM ×2.

## 5. ERC / verification checklist

- [ ] Both `NCHn_V_SW` reach J1; both `NCHn_GND` reach the star then J1; exactly **one** star node.
- [ ] I2C0 → charger 1 only, I2C1 → charger 2 only; 4.7 k pull-ups once per bus, to `+3V3`.
- [ ] ESP rail from `NCH1_V` via AP2112K — never raw VBUS; diode-OR + 2N7002 shunt per v0.5.
- [ ] Each SY6970: TS NTC, ILIM, REGN/PMID/BAT/SYS caps, inductor; `/QON` strapped high.
- [ ] RGB chain: `RGB_DATA` → NCH1 DIN, NCH1 DOUT → NCH2 DIN; `LED_VDD` = `NCH1_V`; /STAT LEDs kept.
- [ ] Pull-pin block: loop in the **positive** path, `_SW` naming downstream, silkscreen labels.
- [ ] CFG strap = 9 V default; ERC clean, PWR_FLAGs placed; footprints assigned (R/C 0603).

## 6. Capture order

1. Open the copied `USB_IN`, retarget the CFG strap to 9 V.
2. ROOT: instantiate `USB_IN` + one `charge_chanel`, wire `VBUS` + `NCH1_V`, ERC.
3. ROOT: draw the ESP block (copy board1 root's as-built diode-OR/AP2112K section, delete the
   TCA9548A, wire the two I²C pairs) + WAKE switch.
4. Add the second `charge_chanel` instance, pull-pin block, J1, star ground, LEDs, straps.
5. Full ERC vs §5 → annotate → footprints → layout (outline waits on sled dims).

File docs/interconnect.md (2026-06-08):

# AURC BMS — Interconnect Contract

**The single source of truth for everything that crosses a board boundary.**

The BMS is now three separately-laid-out KiCad projects (`board1_power`, `board2_monitor`,
`board3_dist`). Nothing but this document guarantees they mate. Treat every pin map below as
**authoritative**: if a board's connector disagrees with this file, the board is wrong, not the
file. Change a pinout here first, in a commit of its own, before touching copper on either side.

Derived from `architecture_v0.2.md` §2–§3, §6, §8. Read those for *why*; read this for *what pin*.

---

## Channels

Four electrically independent 1S channels. One 18650 each. Independent positive rails; returns
join at a **single star point** (location TBD, §13.3), not a shared plane.

| Channel | Load | Pull-pin colour/key | Notes |
|---|---|---|---|
| CH1 | FC1 (primary flight computer) | FC key | ESP module lives on this channel |
| CH2 | FC2 (backup flight computer) | FC key | |
| CH3 | Pyro1 | PYRO key (distinct) | low-Rds protection FET, carries firing pulse |
| CH4 | Pyro2 | PYRO key (distinct) | low-Rds protection FET, carries firing pulse |

Pin-1 / channel-ordering convention used everywhere below: **CH1 → CH2 → CH3 → CH4** (FC1, FC2,
Pyro1, Pyro2), low pin number first. Keep this order identical on both halves of every connector.

---

## Board stack (mechanical, to confirm — §13.1)

```
        loads (FC1/FC2/Pyro1/Pyro2)
              ▲   ▲
          Conn A   Conn B
              │
   ┌──────────────────────┐
   │  Board 3 — Distribution│  passive fan-out
   └──────────┬─────────────┘
        J3  power 8-pin  (through pull-pin enable interface)
              │
   ┌──────────────────────┐
   │  Board 2 — Safe/Monitor│  spine: 64-LED gauge + 4× pull pins
   └───┬──────────────┬─────┘
   J2 power 8-pin   J2s signal 4-pin
       │              │
   ┌──────────────────────┐
   │  Board 1 — Power/Charge│  USB-C, 4× charger, cells, fuel gauges, ESP
   └──────────────────────┘
```

Boards 1 and 3 stack parallel; Board 2 is the spine carrying the gauge and the pull-pin interface.
Board-to-board via **stacking mezzanine connectors** — part/pitch **TBD (§13.1)**. The pin maps
below are logical; assign physical positions once the mezzanine part is chosen, preserving the
CH1→CH4 ordering and keeping each channel's V adjacent to its own GND.

---

## J1 — Board 1 ↔ Board 2  (power, 8-pin)

4× channel rails + 4× returns. **3 A per pin.** Each channel's V paired adjacent to its own GND
(independent returns — do not common the grounds here).

| Pin | Net | Pin | Net |
|---|---|---|---|
| 1 | CH1_V (FC1) | 2 | CH1_GND |
| 3 | CH2_V (FC2) | 4 | CH2_GND |
| 5 | CH3_V (Pyro1) | 6 | CH3_GND |
| 7 | CH4_V (Pyro2) | 8 | CH4_GND |

Each rail is the per-channel **`CHn_V`** output: a `0Ω` strap selects its source — **`SYS`** (SY6970
power-path, **default**) or **`LOAD_P`** (direct protected battery) — and a single PTC fuses it after
the selector. Live whenever a charged cell is fitted (independent of USB). See architecture §4/§5/§12.

## J1s — Board 1 ↔ Board 2  (signal, 4-pin)

I²C to the Board-2 gauge driver, plus the gauge-button **wake** line.

| Pin | Net | Notes |
|---|---|---|
| 1 | SDA | I²C, pulled up 4.7 k on **Board 1** |
| 2 | SCL | I²C, pulled up 4.7 k on **Board 1** |
| 3 | **WAKE** | Board-2 gauge button → Board-1 ESP enable (momentary; the button connects `CH1_V` → `WAKE`, which feeds the ESP-enable diode-OR) |
| 4 | SGND | signal ground reference |

**Board-2 power:** the gauge (IS31FL3731 + LED matrix) is powered **directly from `CH1_V`** via the 8-pin power connector (J1) — no 3V3 pass-through, no Board-2 regulator. The 3.3 V I²C bus is level-compatible across the cell range; the gauge is dark in flight (ESP off → no I²C frames).

**I²C topology:** ESP → TCA9548A → 4× **SY6970** chargers (each addr 0x6B, integrated V/I/charge/TS
monitoring — no separate fuel gauge), all on Board 1. The IS31FL3731 gauge driver on Board 2
(addr **0x74**, no conflict) sits **upstream of the mux** and is reached across J1s. Only SDA/SCL
cross the boundary; the mux and chargers stay on Board 1. Pull-ups (4.7 k) live on Board 1.

> **RESOLVED (§13.2).** The dedicated channel-live line was **dropped** — pin 3 now carries `WAKE`.
> Channel-live state is derived in firmware from the SY6970 I²C readings and streamed over BLE /
> shown on the gauge, so no hardware sense line is needed. J1s stays 4-pin.

---

## J2 — Board 2 ↔ Board 3  (power, 8-pin, through the pull-pin enable interface)

Same 4× V / 4× GND map as J1, **but routed through the four pull-pin power-enable switches on
Board 2.** Pin inserted = channel isolated (safe); pin removed = power flows (*default-unpinned is
live* — use captive/retained pins, §8).

| Pin | Net | Pin | Net |
|---|---|---|---|
| 1 | CH1_V_SW (FC1) | 2 | CH1_GND |
| 3 | CH2_V_SW (FC2) | 4 | CH2_GND |
| 5 | CH3_V_SW (Pyro1) | 6 | CH3_GND |
| 7 | CH4_V_SW (Pyro2) | 8 | CH4_GND |

`_SW` = downstream of the pull-pin switch. Grounds pass straight through (returns stay independent).
**3 A per pin.** Pull pins themselves are 4× 2-pin screw terminals on Board 2, **not** part of this
connector. Key/colour the two PYRO pins distinctly from the two FC pins.

---

## J3 — Board 3 → loads  (distribution fan-out)

Board 3 is passive. It splits the four switched channels into two load connectors, each carrying a
flight computer **and** its paired pyro board. Per-channel V and GND kept separate end-to-end.

### Conn A — FC1 + Pyro1
| Pin | Net |
|---|---|
| 1 | FC1_V (= CH1_V_SW) |
| 2 | FC1_GND  (= CH1_GND)  |
| 3 | PYRO1_V  (= CH3_V_SW) |
| 4 | PYRO1_GND(= CH3_GND)  |

### Conn B — FC2 + Pyro2
| Pin | Net |
|---|---|
| 1 | FC2_V (= CH2_V_SW) |
| 2 | FC2_GND  (= CH2_GND)  |
| 3 | PYRO2_V  (= CH4_V_SW) |
| 4 | PYRO2_GND(= CH4_GND)  |

The BMS delivers power only — **no arming, no pyro circuitry** on any of these three boards. Firing
FETs, opto-isolation, e-match continuity all live on the downstream pyro boards. The BMS must
deliver clean, transient-free power so applying it can't glitch a load (size input caps + soft-start
on Board 1, §8).

---

## Net-name conventions (use these exact labels on hierarchical pins / global labels)

- `CH{1..4}_V`      — protected, charge-side rail, Board 1 output → J1
- `CH{1..4}_V_SW`   — same rail after the Board-2 pull-pin switch → J2/J3
- `CH{1..4}_GND`    — that channel's independent return (star-bonded at one point only)
- `SDA` / `SCL`     — I²C bus (4.7 k pull-ups on Board 1)
- `WAKE`            — Board-2 gauge button → Board-1 ESP enable (momentary; replaced `CH_LIVE`)
- `SGND`            — signal/I²C reference

Star-point: bond the four `CH*_GND` returns at exactly **one** location (likely Board 1 by the
cells, §13.3) via per-channel ground-to-star 0 Ω links (§12). Nowhere else.

---

## Open items affecting this contract

1. **§13.1** Mezzanine connector part + pitch → fixes physical pin assignment of J1/J1s/J2.
2. ~~**§13.2** Channel-live sense granularity~~ **RESOLVED** — line dropped; pin 3 = `WAKE`, channel-live derived in firmware.
3. **§13.3** Star-point location → which board carries the ground-to-star 0 Ω links.

When any of these closes, edit this file **first**, in its own commit, then update both board edges.

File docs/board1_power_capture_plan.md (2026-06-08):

# Board 1 — Power & Charge — Schematic Capture Plan

Capture plan for `board1_power/board1_power.kicad_sch`. Draw it in KiCad from this; it's the
engineering, not the drawing. Authority order: `interconnect.md` (board edges) → `architecture.md`
(design intent) → this file (Board 1 detail).

**Locked decisions (2026-06-08):** SY6970 smart charger (charge + integrated I²C monitoring, no
separate fuel gauge) · ESP32-S3-WROOM-1 · TCA9548A I²C mux · 4 independent 1S channels (FC1, FC2,
Pyro1, Pyro2) · single star ground on Board 1.

> **Build status (2026-06-08):** the drawn capture was **migrated** from the archived single-board
> design into `board1_power/` — `USB_IN.kicad_sch` and the 4× `charge_chanel.kicad_sch` instances
> are live (lib refs fixed to `BMS:`), validated by `kicad-cli sch erc` (loads clean, 169 WIP
> violations — unconnected pins, no PWR_FLAGs, "Unspecified" pin-type warnings from the imported
> symbols). **Remaining build (do in KiCad GUI, in order):** ① swap ESP32-C3 → ESP32-S3-WROOM-1 ·
> ② add TCA9548A mux + wire each channel's I²C to its mux port (§5 table) · ③ add the 4× RGB chain +
> TPS22917 load switch (§5, §9b) · ④ add J1 / J1s connectors (§6, `interconnect.md`) · ⑤ star
> ground (§7) · ⑥ finish root wiring, add PWR_FLAGs, place the 2nd unit of the dual FET, clear ERC.

> **Pin numbers:** connections below are given **by pin function/name**, because the safe move is
> to confirm physical pin numbers against each part's symbol + datasheet as you place it. For the
> charge channel and USB input you already have a *drawn reference* in
> `_archive/single-board-v0.1/` (`charge_chanel.kicad_sch`, `USB_IN.kicad_sch`) — open it alongside.

---

## 0. What lives on Board 1

USB-C input + PD sink · 4× SY6970 power-path chargers (+ per-cell protection + 18650) · ESP32-S3 +
TCA9548A mux + 3V3 LDO behind a load switch · hardwired indicator LEDs · the two board-edge
connectors **J1** (8-pin power out) and **J1s** (4-pin signal). Star ground is here.

Nothing flight-critical depends on the ESP. The four SYS rails leave via J1 regardless of ESP state.

---

## 1. Sheet hierarchy

```
board1_power.kicad_sch  (ROOT)
├── usb_in.kicad_sch              ×1   USB-C + CH224K PD sink + ESD + input caps
├── charge_channel.kicad_sch      ×4   one per cell — SY6970 + protection + 18650   ← reusable design
└── esp_monitor.kicad_sch         ×1   ESP32-S3 + TCA9548A mux + AP2112K 3V3 + TPS22917 load switch
ROOT also holds: J1, J1s, star-ground node, fault LED, the global rails.
```

Use **one** `charge_channel` sheet file, instantiated 4×. Per-instance differences (which load,
which mux channel, pin colour) are wired at the root via sheet pins — the sheet itself is generic.

**Sheet pins (the contract between each sub-sheet and root):**

| Sheet | In | Out / bidir |
|---|---|---|
| `usb_in` | — | `VBUS` (PD rail, ~12 V), `USB_DP`, `USB_DM`, `GND` |
| `charge_channel` | `VBUS`, `SDA_n`, `SCL_n`, `RGB_DIN`, `LED_VDD`, `GND` | `CHn_V` (= SYS rail), `STATn`, `RGB_DOUT` |
| `esp_monitor` | `VBUS_PRESENT`/`SYS_FC1` (ESP rail source), `SDA`,`SCL` (main bus), `USB_DP`,`USB_DM`, `GND` | `SDA0..3`,`SCL0..3` (mux downstream → the 4 channels), `MUX_RST`, `RGB_DATA` (to first cell's `RGB_DIN`) |

**Per-cell RGB chain:** the ESP's `RGB_DATA` → instance 1's `RGB_DIN`; each instance's `RGB_DOUT` →
the next instance's `RGB_DIN` (daisy chain, one data line for all four). `LED_VDD` is the **SYS/charge
rail**, *not* `+3V3`. See §9b of `architecture.md` for colour semantics.

> `SDA_n`/`SCL_n` on each `charge_channel` instance connect to a **different** mux downstream pair
> (`SDA0/SCL0` → channel 1, … `SDA3/SCL3` → channel 4). That's how four identical 0x6B chargers
> coexist. Keep the channel→mux-port mapping fixed and documented (table in §6).

---

## 2. Global nets / naming (match `interconnect.md`)

| Net | Meaning |
|---|---|
| `VBUS` | PD-negotiated input rail (~12 V) feeding all four chargers + the ESP rail source |
| `CH1_V`..`CH4_V` | each channel's SYS rail (charger output) → J1. **= FC1, FC2, Pyro1, Pyro2** |
| `CH1_GND`..`CH4_GND` | each channel's independent return → star point (§7) → J1 |
| `SDA`,`SCL` | ESP main I²C bus (4.7 k pull-ups on Board 1) |
| `SDA0..3`,`SCL0..3` | mux downstream pairs → the four SY6970s |
| `MUX_RST` | ESP → TCA9548A reset (active low) |
| `USB_DP`,`USB_DM` | USB D+/D- → ESP native USB |
| `+3V3` | ESP/logic rail (LDO output, downstream of load switch) |
| `CH_LIVE` | combined channel-live sense → J1s (see open item §13.2) |
| `STAT1..4` | per-channel /STAT (to hardwired fallback LEDs) |
| `RGB_DATA` → `RGB_DIN/DOUT` chain | per-cell addressable RGB status, daisy-chained (§9b) |
| `LED_VDD` | RGB LED supply = **SYS/charge rail** (not +3V3) |

---

## 3. Sheet `usb_in` — USB-C + PD sink  (reuse archived `USB_IN.kicad_sch` ~as-is)

This already matches v0.3. Components: `Connector:USB_C_Receptacle_USB2.0_16P`, `BMS:CH224K`,
`Power_Protection:USBLC6-2SC6`, input bulk cap (`Device:C_Polarized`), decoupling, status LED.

Connections (by function — confirm pins):

- **USB-C** VBUS pins (A4/A9/B4/B9) → `VBUS_RAW`; GND pins (A1/A12/B1/B12) + shield → `GND`.
- **CC1/CC2** → CH224K CC1/CC2. **D+/D-** → through USBLC6 → `USB_DP`/`USB_DM` (series 0Ω strap each).
- **CH224K**: VBUS in ← `VBUS_RAW`; VOUT/sense → `VBUS`; **CFG/PG resistor strap sets the requested
  voltage** (9/12/15 V — populate per §8); decouple VDD. PG/status → input-present LED (green).
- **USBLC6** across D+/D- and VBUS for ESD; one device covers both data lines + VBUS clamp.
- Input bulk cap on `VBUS` (hot-plug inrush, §8) + soft-start consideration at the board level.

Sheet-pin out: `VBUS`, `USB_DP`, `USB_DM`, `GND`.

> Note: CH224K negotiates *input* voltage. Per-channel charge regulation is the SY6970's job.

---

## 4. Sheet `charge_channel` (×4) — SY6970 + protection + cell

**You already drew this** (archived `charge_chanel.kicad_sch`: SY6970QCC + DW01A + SI4920DY +
AO3401A + SRP5030 + Polyfuse + NTC + STAT LED). Re-draw it into the new project (capture-plan-only),
or open the archive as your template. Target net list per instance:

**Components:** `BMS:SY6970QCC` (U), `Battery_Management:DW01A` (U), `BMS:SI4920DY` dual N-FET (Q),
`Transistor_FET:AO3401A` P-FET (Q, reverse-polarity), `BMS:SRP5030CA-2R2M` 2.2µH (L),
`Device:Polyfuse` PTC (F), `Device:Thermistor_NTC` (RT), `Device:LED` (D, /STAT hardwired fallback),
**SK6812/WS2812B addressable RGB (D, per-cell status — §9b)**, 18650 holder
(`Connector`/`Device:Battery`), input/output caps, ILIM + TS divider + I²C-section resistors.

**Power path (cell → SYS):**
1. **18650** `CELL_P` / `CELL_N`.
2. **Protection (DW01A + SI4920DY)** in the cell-negative line: the two series N-FETs sit between
   `CELL_N` and the channel's protected negative (`B_MINUS`). DW01A: VDD←`CELL_P` (via 100Ω+0.1µF
   RC), GND←`B_MINUS`, CS/Vm← the FET-junction node, OC/OD gates → SI4920DY gates. *(Canonical DW01A
   1S circuit — mirror the archived sheet.)* Over-charge ~4.3 V, over-discharge ~2.4 V, OC trip set
   by FET Rds. **Pyro channels: use the lower-Rds FET option** so the firing pulse doesn't trip OC.
3. **Reverse-polarity P-FET (AO3401A)** in the protected positive line: source→`CELL_P`, drain→
   `VBAT_PROT`, gate→`B_MINUS` via 100k. (Consider DMG2305UX/SI2333 for lower Rds — §11.)
4. **PTC fuse** in series (positive line) — sized above the 2 A firing pulse, below sustained short.
5. **SY6970**: `BAT` ↔ `VBAT_PROT`; `SW` → inductor `L` → ; `SYS` → **`CHn_V`** (sheet-pin out, the
   J1 rail); `VBUS` ← global `VBUS`; `PMID` cap to GND; `REGN` cap; `ILIM` resistor to GND (input
   current limit); `TS` ← NTC divider (charge temp cutoff 0–45 °C); `/STAT` → STAT LED **and**
   sheet-pin `STATn`; `/CE` tie enabled (or ESP GPIO later); `SDA`/`SCL` ← sheet-pins `SDA_n`/`SCL_n`
   (this channel's mux pair); `OTG`/boost unused — tie per datasheet; D+/D- on SY6970 unused (PD is
   handled upstream) — terminate per datasheet.
6. **Decoupling:** VBUS in-cap, SYS out-cap, BAT cap, REGN/PMID caps per SY6970 datasheet.

**Ground:** this channel's return is `CHn_GND` — kept independent, joined only at the star (§7).

**RGB status LED (§9b):** one SK6812/WS2812B per cell. `VDD` ← `LED_VDD` (SYS rail) + 0.1µF;
`DIN` ← sheet-pin `RGB_DIN`; `DOUT` → sheet-pin `RGB_DOUT`; `GND` ← `CHn_GND`. The dumb `/STAT` LED
stays as the firmware-independent fallback.

Sheet-pins: in `VBUS`,`SDA_n`,`SCL_n`,`RGB_DIN`,`LED_VDD`,`GND` · out `CHn_V`,`STATn`,`RGB_DOUT`.

---

## 5. Sheet `esp_monitor` — ESP32-S3 + mux + 3V3 + load switch

**This is the main *new* capture work** (archived top sheet was ESP32-C3 + AP2112K; upgrade to S3
and add the mux + load switch).

**Components:** `RF_Module:ESP32-S3-WROOM-1` (U), `Interface_Expansion:TCA9548APWR` (U),
`Regulator_Linear:AP2112K-3.3` (U), `Power_Switch:TPS22917...` load switch (U), I²C pull-ups,
decoupling, BOOT/EN parts, optional gauge button input.

**ESP rail gating (the hard gate, §7 of architecture):**
- ESP-rail source = charge/SYS rail (strap-select SYS_FC1 vs charge rail — §8), **never raw VBUS**.
- That source → **TPS22917 load switch** (ON pin driven by: USB-present OR gauge-button latch OR
  launch-day jumper — see arch §7 states) → **AP2112K-3.3** → `+3V3` → ESP `3V3` + decoupling.
- TPS22917 is the real gate firmware can't defeat; add a watchdog/timeout downstream.

**ESP32-S3:**
- `3V3` ← `+3V3`; multiple `GND`; `EN` pull-up + RC; `IO0`(BOOT) pull-up + button/pad.
- **Native USB:** `USB_D+`/`USB_D-` ← `USB_DP`/`USB_DM` (programming over USB-Serial-JTAG; no UART
  bridge). USBLC6 ESD is on the usb_in sheet.
- **I²C main bus:** two GPIO → `SDA`/`SCL` (4.7 k pull-ups to +3V3 *here*).
- `MUX_RST` → one GPIO. Optional `/INT` aggregation from chargers → one GPIO.
- **`RGB_DATA` → one GPIO → first cell's `RGB_DIN`** (per-cell RGB chain, §9b). If WS2812B, put a
  level shifter (74AHCT125 / SN74LVC2T45) on this line; SK6812 usually tolerates 3.3 V direct. Add a
  ~330 Ω series resistor at the source and a bulk cap on `LED_VDD`.
- Optional: gauge-button input GPIO; STAT sense GPIOs (telemetry) — non-critical.

**TCA9548A mux:**
- `VCC`←`+3V3`, decouple; `A0/A1/A2` → address straps (pick 0x70); `/RESET`←`MUX_RST`.
- **Upstream** `SDA`/`SCL` ← ESP main bus `SDA`/`SCL`.
- **Downstream** SD0/SC0..SD3/SC3 → `SDA0/SCL0`..`SDA3/SCL3` (sheet-pins to the 4 channels).
- The Board-2 IS31FL3731 (0x74) sits on the **main** bus (upstream of mux) and exits via J1s — it is
  *not* on a mux channel (unique address, no conflict).

**Mux-channel ↔ cell map (fix this and don't change it):**

| Mux ch | Pair | Channel | Load |
|---|---|---|---|
| 0 | SDA0/SCL0 | CH1 | FC1 |
| 1 | SDA1/SCL1 | CH2 | FC2 |
| 2 | SDA2/SCL2 | CH3 | Pyro1 |
| 3 | SDA3/SCL3 | CH4 | Pyro2 |
| 4–7 | — | spare | — |

Sheet-pins: in `ESP_RAIL_SRC`,`SDA`,`SCL`,`USB_DP`,`USB_DM`,`GND` · out `SDA0..3`,`SCL0..3`,`MUX_RST`,`RGB_DATA`.

---

## 6. ROOT sheet — instances, connectors, star ground

- Place the 6 sheet instances (1× usb_in, 4× charge_channel, 1× esp_monitor).
- Wire each `charge_channel` instance's `SDA_n`/`SCL_n` to its mux pair per the table above.
- Bus `VBUS` from usb_in → all four charge_channels + esp_monitor rail source.
- **J1 — power, 8-pin** (`Connector_Generic:Conn_02x04` or chosen mezzanine):
  `CH1_V`/`CH1_GND` … `CH4_V`/`CH4_GND`, pin order = interconnect.md §J1, 3 A/pin.
- **J1s — signal, 4-pin:** `SDA`, `SCL`, `CH_LIVE`, `SGND`.
- **`CH_LIVE`** (combined): derive from a diode-OR of the four SYS rails through a divider to a
  logic-level sense (or revisit §13.2 if per-channel is needed). Mark as provisional.
- **Fault LED** (board-level) + input-present LED (on usb_in).

---

## 7. Star ground (architecture §3)

The four `CHn_GND` returns are **independent** up to a single star node on Board 1 (by the cells).
Join them there with per-channel `0Ω` links (§8 strap) — and reference USB `GND` and signal `SGND`
to that same node. **Nowhere else.** Do not pour one continuous ground plane across all four
channels; keep four return regions meeting at the star. This is the OZONE PYRO_GND philosophy.

---

## 8. Config straps (architecture §12 — place as 0Ω / DNP pads)

- **PD voltage request** (CH224K CFG): 9 / 12 / 15 V — default 12 V.
- **PD-sink bypass** (force 5 V) for a dumb host.
- **D+/D- series 0Ω** (×2) — isolate ESP USB if needed.
- **ESP rail source select** (charge-rail vs cell-1) + **always-on capability** strap.
- **SY6970 ILIM resistor** per channel (input-current limit; charge current itself is I²C-set).
- **Per-channel ground-to-star 0Ω** (×4) — the star links.
- **Per-channel enable source** (`/CE` from pull vs always-on for bench).

---

## 9. Library / symbol map

| Need | Symbol | Source | Status |
|---|---|---|---|
| Charger+monitor | `SY6970QCC` | `libs/BMS.kicad_sym` | ✓ have |
| Inductor 2.2µH | `SRP5030CA-2R2M` | `libs/BMS.kicad_sym` | ✓ have |
| PD sink | `CH224K` | `libs/BMS.kicad_sym` | ✓ have |
| Protection FET | `SI4920DY` | `libs/BMS.kicad_sym` | ✓ have |
| Protection IC | `DW01A` | `Battery_Management` | ✓ stock |
| Rev-polarity P-FET | `AO3401A` (or DMG2305UX) | `Transistor_FET` | ✓ stock (AO3401A) |
| ESP | `ESP32-S3-WROOM-1` | `RF_Module` | ✓ stock |
| I²C mux | `TCA9548APWR` | `Interface_Expansion` | ✓ stock |
| 3V3 LDO | `AP2112K-3.3` | `Regulator_Linear` | ✓ stock |
| Load switch | `TPS22917...` | `Power_Switch` | ✓ stock (pick variant) |
| ESD | `USBLC6-2SC6` | `Power_Protection` | ✓ stock |
| Per-cell RGB ×4 | `SK6812` / `SK6812MINI-E` / `WS2812B` | `LED` | ✓ stock (confirm footprint variant) |
| LED level shifter (opt) | `74AHCT1G125` | `74xGxx` | ✓ stock; only if WS2812B |
| USB-C | `USB_C_Receptacle_USB2.0_16P` | `Connector` | ✓ stock |
| PTC / NTC / R / C / LED | `Device:*` | `Device` | ✓ stock |
| 18650 holder | `Device:Battery` / `Connector` | `Device` | ✓ stock |

**Footprints to confirm before layout:** SY6970 package (QFN — already in `BMS.pretty`?), TCA9548APWR
(TSSOP-24), ESP32-S3-WROOM-1 (RF_Module.pretty), TPS22917 (SOT-23-6), DW01A (SOT-23-6), SI4920DY
(SOIC-8 — in `BMS.pretty`), AO3401A (SOT-23). No new *symbols* need creating — good.

---

## 10. ERC / verification checklist

- [ ] All four `CHn_V` reach J1; all four `CHn_GND` reach the star then J1.
- [ ] Exactly **one** star node; no second ground tie between channels.
- [ ] I²C: 4.7 k pull-ups present once (on +3V3 main bus); each SY6970 on its own mux channel;
      gauge driver (0x74) on main bus, not a mux channel; `MUX_RST` driven.
- [ ] ESP rail comes through the load switch + LDO, **never raw VBUS**; load switch ON logic correct.
- [ ] Each SY6970 has TS NTC, ILIM resistor, REGN/PMID/BAT/SYS caps, inductor on SW.
- [ ] Pyro-channel protection FET is the low-Rds option (won't trip on firing pulse).
- [ ] RGB chain: `RGB_DATA`→cell1 `DIN`, each `DOUT`→next `DIN`; `LED_VDD` = SYS rail (not +3V3);
      series R + level shift present if WS2812B; hardwired `/STAT` LED still present per cell.
- [ ] No power-flag/unconnected ERC errors; every hierarchical sheet pin matches its label.
- [ ] J1 / J1s pinout byte-for-byte matches `interconnect.md`.
- [ ] PD CFG strap set to a sane default (12 V); bypass-to-5V strap present.

---

## 11. Suggested capture order

1. `usb_in` (smallest, reuse archived) → get `VBUS` clean.
2. `charge_channel` ×1 (reuse archived; review against §4) → ERC one channel in isolation.
3. ROOT: instantiate that one channel + usb_in, verify `VBUS` + one `CHn_V`.
4. `esp_monitor` (the new work: S3 + mux + load switch).
5. ROOT: wire mux↔channel I²C, add the other 3 channel instances, J1, J1s, star ground, LEDs.
6. Full ERC pass against §10. Then annotate + assign footprints → ready for layout.

---

## 12. Open items that touch Board 1

- **§13.2** `CH_LIVE` combined vs per-channel → J1s pin count + the root sense circuit.
- **§13.3** Star-point exact location in copper (this plan assumes Board 1 by the cells).
- **§13.4** Pyro OC trip: verify firing inrush vs chosen SI4920DY Rds + PTC rating vs the e-match.
- Confirm SY6970 footprint + LCSC stock; confirm TPS22917 variant (latching vs non-latching ON).

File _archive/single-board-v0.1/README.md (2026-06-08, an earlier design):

# Archived — single-board attempt (v0.1)

This is the original **single-board** AURC_BMS layout, archived on 2026-06-08 when the design was
split into the three-board set (`board1_power`, `board2_monitor`, `board3_dist`) per
`docs/architecture_v0.2.md`.

Kept for reference only — do **not** continue work here.

Contents:
- `AURC_BMS.kicad_pro` / `.kicad_sch` / `.kicad_pcb` — top-level single-board project
- `charge_chanel.kicad_sch`, `USB_IN.kicad_sch` — hierarchical sheets (per-channel charger, USB input)
- `sym-lib-table`, `fp-lib-table` — original project-local lib tables (referenced the
  `easyeda2kicad` library nicknames, since renamed to `BMS` and relocated to `../../libs/`)

The schematics embed their symbol definitions (`lib_symbols`), so they still open and display even
though the library was renamed. Footprint/3D-model links may not resolve against the new `libs/`
layout — expected, since this is frozen reference material.

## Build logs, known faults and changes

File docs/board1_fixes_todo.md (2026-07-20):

# Board 1 (main power board) — outstanding fixes

Found while building board4 (nosecone), which was copied from board1 — these bugs exist on
**board1_power** too and need fixing there. Board1 already has placed copper, so both are a
schematic **and** layout touch.

## 1. PD voltage-select straps incomplete (CFG2/CFG3 floating)

`board1_power/USB_IN.kicad_sch` — the CH224K is **not deterministically set to 12 V**. As drawn:
- CFG1 → 24 K to GND = logic 0 ✅
- **CFG2 → floating** ✗
- **CFG3 → floating** ✗

Floating CFG pins have no reliable internal default (datasheet: "add external pull-up/pull-down to
set CFG2/CFG3"), so the negotiated voltage is undefined — it may sit at 5/9/12 V unpredictably. The
4-cell board needs a real 12 V (≈30 W budget; a 9 V/2 A phone brick can't feed it), so silently
running at 9 V would input-current-limit and charge slow.

**Fix — set 12 V (CFG1=0, CFG2=0, CFG3=1):**
- CFG2 → **0 Ω to GND** (`R_0603_1608Metric`)
- CFG3 → **~10 K pull-up to `VDD_PD`** (the CH224K's own VDD rail, **not** VBUS and **not** +3V3 —
  must be ≤3.7 V; VDD_PD is alive the instant the chip powers, so no timing dependency)

*(For reference, board4/nosecone uses 9 V = all three CFG to GND — simpler, no pull-up needed.)*

## 2. Heartbeat LED has no series resistor

`board1_power` root — the heartbeat LED **D1** is wired ESP `IO2` (pin 38) → D1 → GND with **no
current-limiting resistor**. An LED straight across a 3.3 V GPIO is limited only by the pin's drive
strength (ESP32-S3 ~40 mA abs max) — stresses the GPIO and over-drives the LED.

**Fix:** insert a series resistor, `IO2 → R → D1 anode`, D1 cathode → GND.
- **1 kΩ** recommended (≈1.3 mA, plenty for a status blink, easy on the battery), `R_0603_1608Metric`.
- (This same bug was pasted into board4 and is being fixed there too.)

---

*Both fixes were identified 2026-07-21. Neither blocks the board from powering, but #1 means the
charge voltage is wrong/undefined and #2 stresses a GPIO — do both before the next board1 revision.*

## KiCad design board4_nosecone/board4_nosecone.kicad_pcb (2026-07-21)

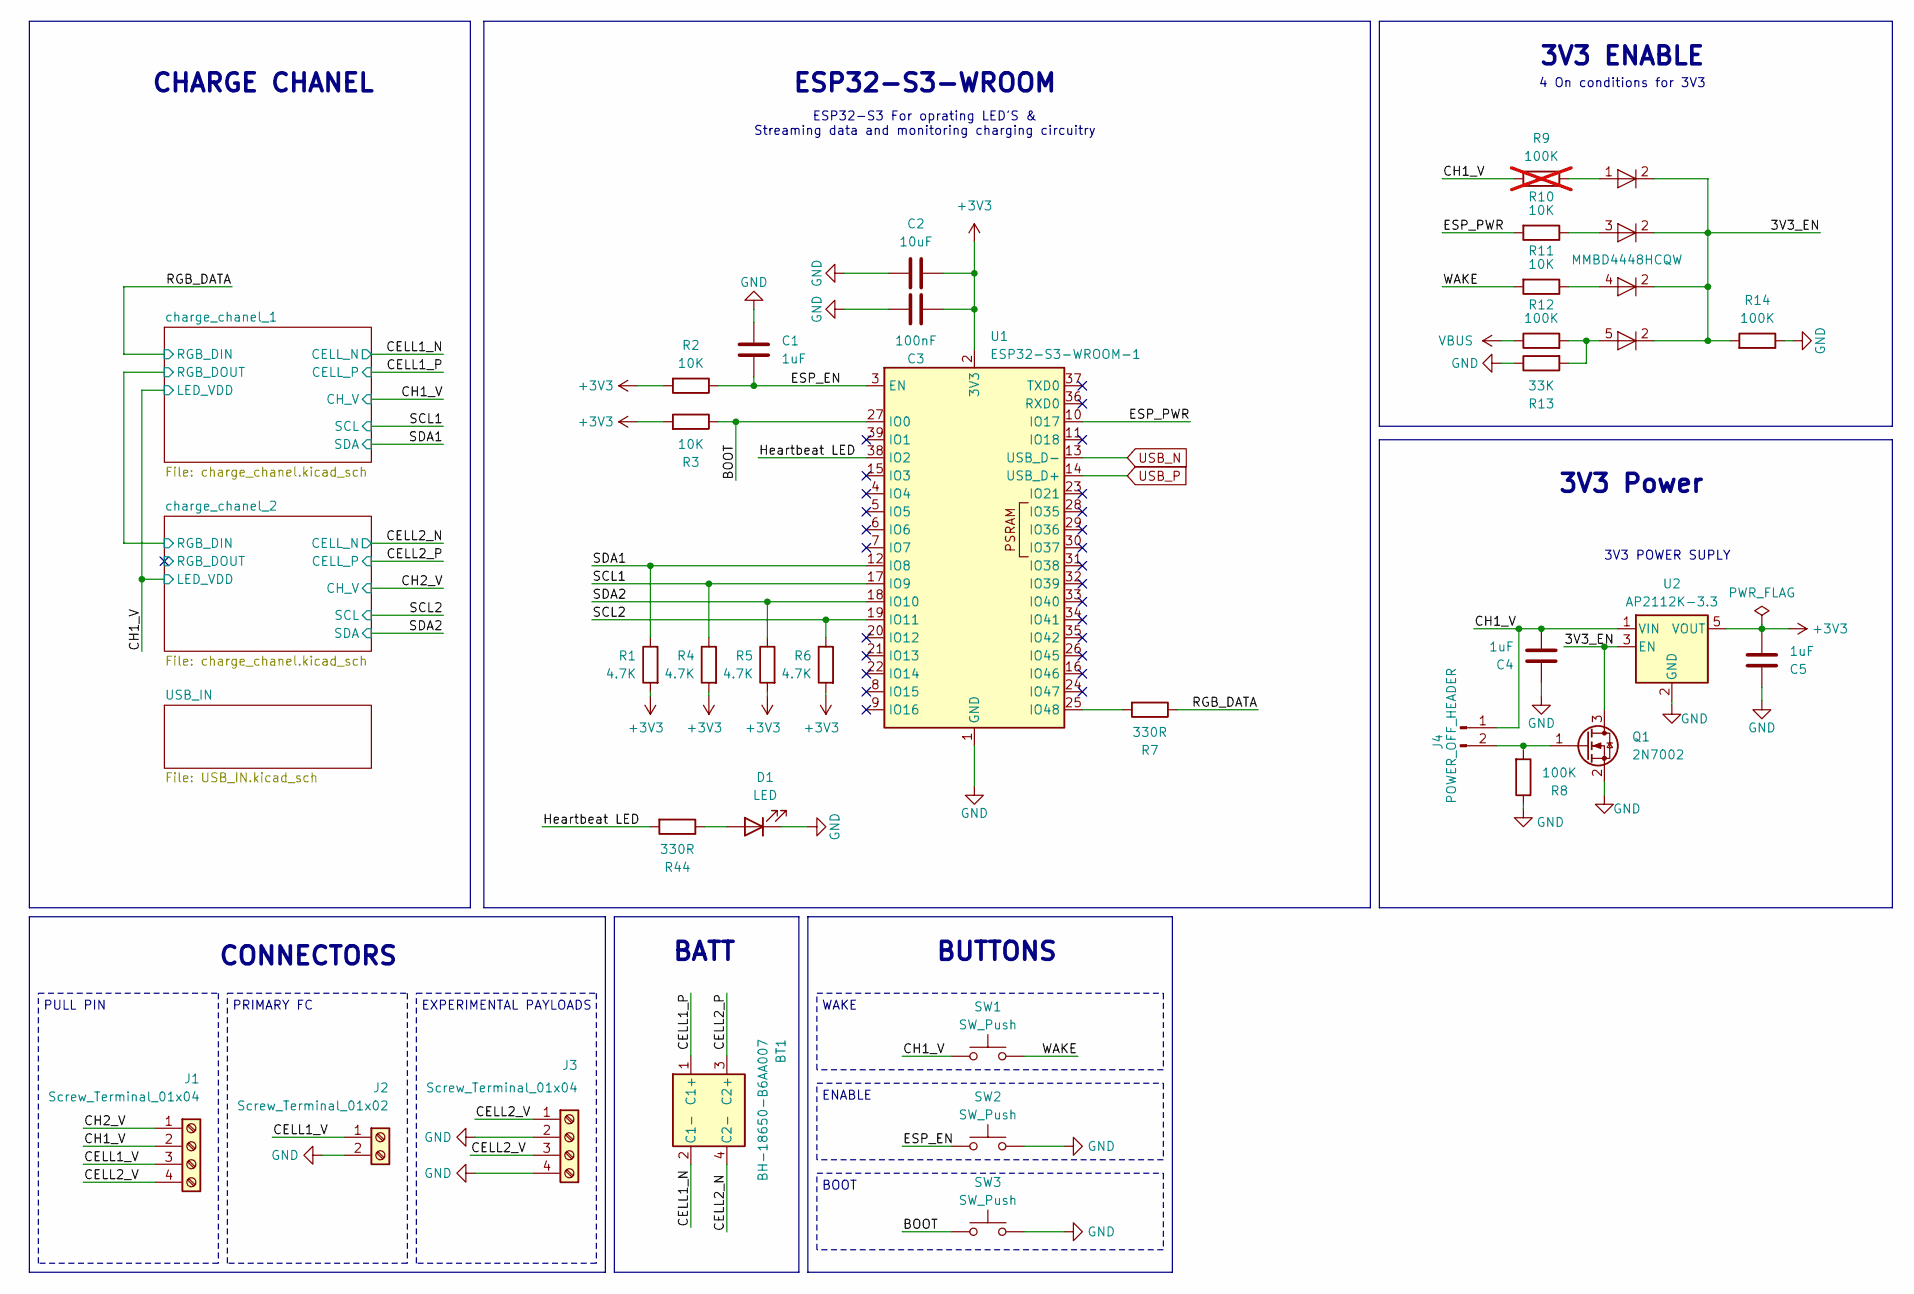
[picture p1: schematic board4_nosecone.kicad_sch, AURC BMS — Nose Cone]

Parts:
BT1: BH-18650-B6AA007
C1: 1uF; C_0603_1608Metric
C2: 10uF; C_0805_2012Metric
C3: 100nF; C_0805_2012Metric
C4, C5: 1uF; C_0805_2012Metric
D1: LED; LED_0603_1608Metric
D2: MMBD4448HCQW; SOT-353_SC-70-5
J1, J3: Screw_Terminal_01x04; TerminalBlock_Phoenix_PT-1,5-4-3.5-H_1x04_P3.50mm_Horizontal
J2: Screw_Terminal_01x02; TerminalBlock_Phoenix_PT-1,5-2-3.5-H_1x02_P3.50mm_Horizontal
J4: POWER_OFF_HEADER; PinHeader_1x02_P2.54mm_Horizontal
Q1: 2N7002; SOT-23
R1, R4, R5, R6: 4.7K; R_0603_1608Metric
R2, R3, R10, R11: 10K; R_0603_1608Metric
R7, R44: 330R; R_0603_1608Metric
R8, R12, R14: 100K; R_0603_1608Metric
R9: 100K; R_0603_1608Metric; not fitted
R13: 33K; R_0603_1608Metric
SW1, SW2, SW3: SW_Push; SW_Push_1P1T_NO_CK_KMR2
U1: ESP32-S3-WROOM-1
U2: AP2112K-3.3; SOT-23-5

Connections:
+3V3: C2.1, C3.1, C5.1, R1.2, R2.2, R3.2, R4.2, R5.2, R6.2, U1.2 (3V3), U2.5 (VOUT); also elsewhere on the board
/3V3_EN: D2.2 (K), Q1.3 (D), R14.2, U2.3 (EN)
/BOOT: R3.1, SW3.1, U1.27 (IO0)
/CELL1_N: BT1.2 (C1-); also elsewhere on the board
/CELL1_P: BT1.1 (C1+); also elsewhere on the board
/CELL1_V: J1.3, J2.1
/CELL2_N: BT1.4 (C2-); also elsewhere on the board
/CELL2_P: BT1.3 (C2+); also elsewhere on the board
/CELL2_V: J1.4, J3.1, J3.3
/CH1_V: C4.1, J1.2, J4.1, R9.1, SW1.1, U2.1 (VIN); also elsewhere on the board
/CH2_V: J1.1; also elsewhere on the board
/ESP_EN: C1.2, R2.1, SW2.1, U1.3 (EN)
/ESP_PWR: R10.2, U1.10 (IO17)
/Heartbeat LED: R44.2, U1.38 (IO2)
/RGB_DATA: R7.1; also elsewhere on the board
/SCL1: R4.1, U1.17 (IO9); also elsewhere on the board
/SCL2: R6.1, U1.19 (IO11); also elsewhere on the board
/SDA1: R1.1, U1.12 (IO8); also elsewhere on the board
/SDA2: R5.1, U1.18 (IO10); also elsewhere on the board
/WAKE: R11.2, SW1.2
GND: C1.1, C2.2, C3.2, C4.2, C5.2, D1.1 (K), J2.2, J3.2, J3.4, Q1.2 (S), R8.1, R13.1, R14.1, SW2.2, SW3.2, U1.1 (GND), U1.40 (GND), U1.41 (GND), U2.2 (GND); also elsewhere on the board
unnamed: D1.2 (A), R44.1
unnamed: D2.1 (A), R9.2
unnamed: D2.3 (A), R10.1
unnamed: D2.4 (A), R11.1
unnamed: D2.5 (A), R12.2, R13.2
unnamed: J4.2, Q1.1 (G), R8.2
unnamed: R7.2, U1.25 (IO48)
USB_N: U1.13 (USB_D-); also elsewhere on the board
USB_P: U1.14 (USB_D+); also elsewhere on the board
VBUS: R12.1; also elsewhere on the board

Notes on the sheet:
BUTTONS
CHARGE CHANEL
3V3 Power
4 On conditions for 3V3
ESP32-S3 For oprating LED'S & Streaming data and monitoring charging circuitry
ESP32-S3-WROOM
ENABLE
3V3 POWER SUPLY
PRIMARY FC
3V3 ENABLE
EXPERIMENTAL PAYLOADS
BATT
CONNECTORS
PULL PIN
BOOT
WAKE

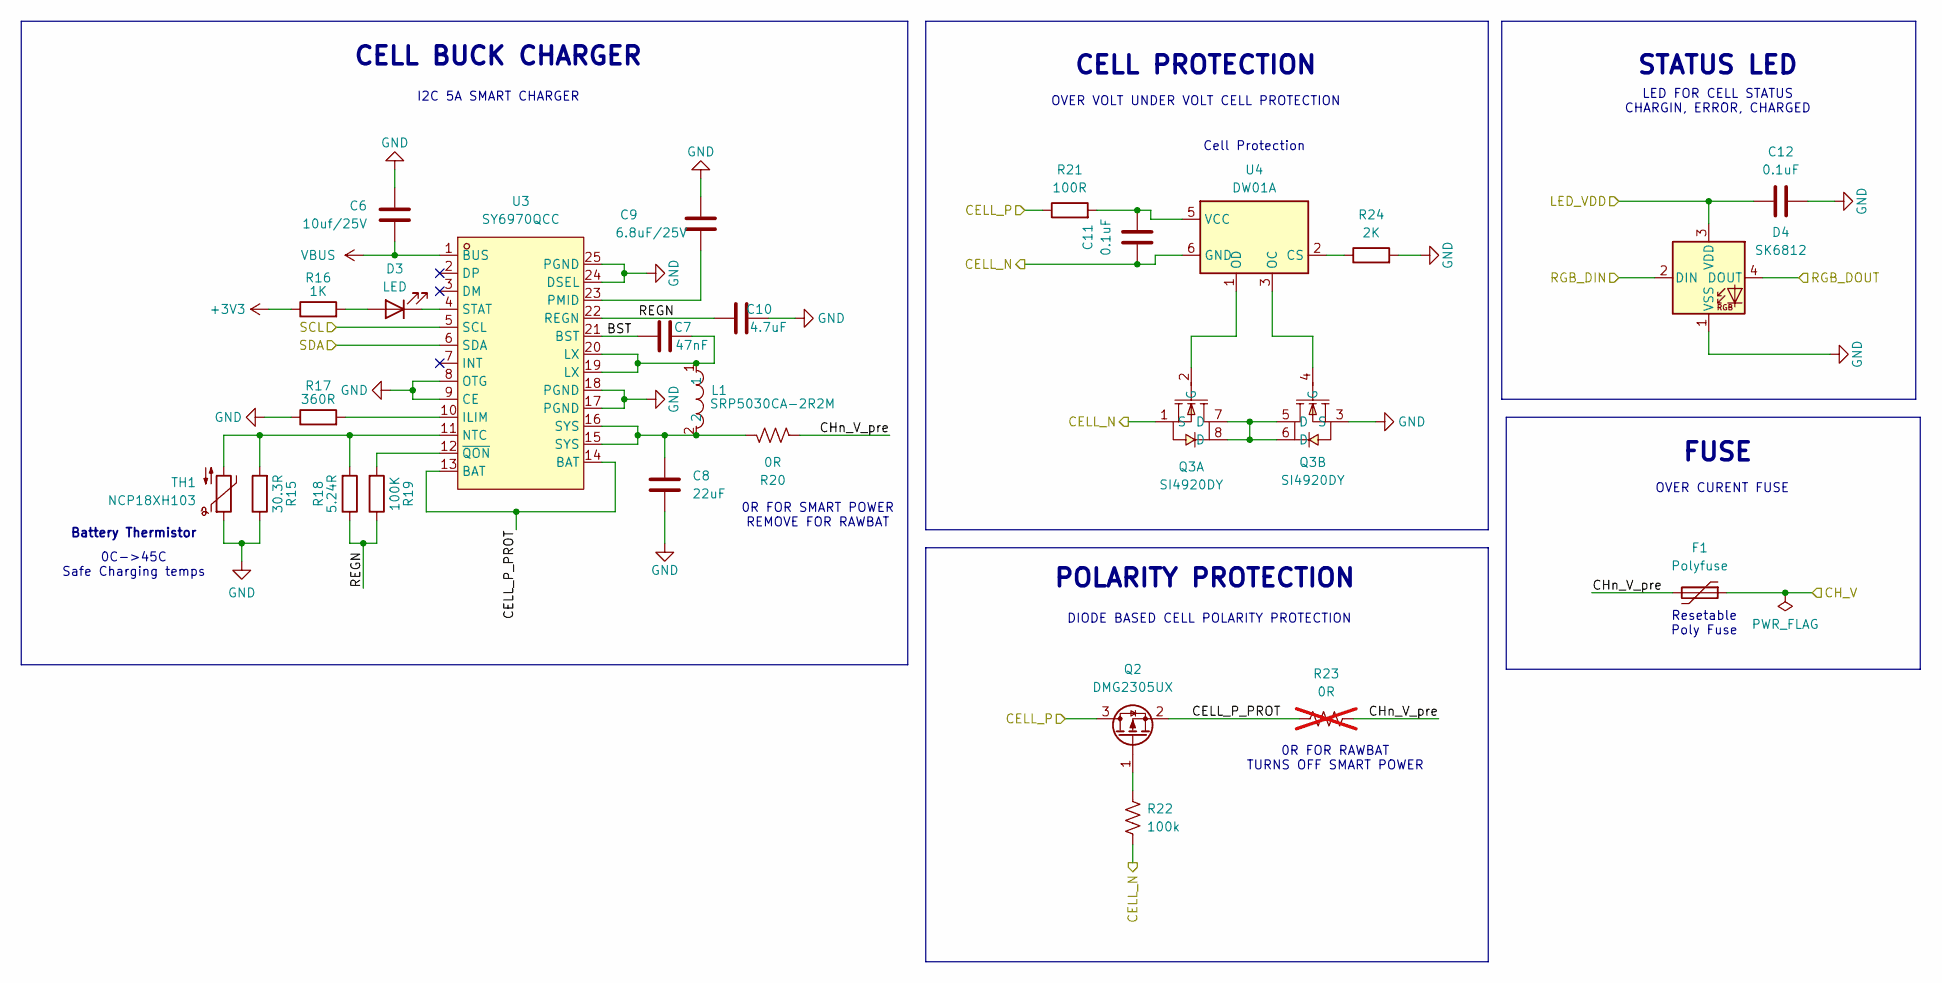
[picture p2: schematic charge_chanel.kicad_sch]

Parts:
C6: 10uf/25V; C_1206_3216Metric
C7: 47nF; C_0805_2012Metric
C8: 22uF; C_1206_3216Metric
C9: 6.8uF/25V; C_0805_2012Metric
C10: 4.7uF; C_0805_2012Metric
C11, C12: 0.1uF; C_0603_1608Metric
D3: LED; LED_0603_1608Metric
D4: SK6812; LED_SK6812_PLCC4_5.0x5.0mm_P3.2mm
F1: Polyfuse; Fuse_1812_4532Metric
L1: SRP5030CA-2R2M; IND-SMD_L5.5-W5.3; MPN SRP5030CA-2R2M; LCSC Part C2046809
Q2: DMG2305UX; SOT-23
Q3: SI4920DY; SOIC-8_L4.9-W3.9-P1.27-LS6.2-BL; MPN SI4920DY; LCSC Part C3289759
R15: 30.3R; R_0603_1608Metric
R16: 1K; R_0603_1608Metric
R17: 360R; R_0603_1608Metric
R18: 5.24R; R_0603_1608Metric
R19: 100K; R_0603_1608Metric
R20: 0R; R_2010_5025Metric
R21: 100R; R_0603_1608Metric
R22: 100k; R_0603_1608Metric
R23: 0R; R_2010_5025Metric; not fitted
R24: 2K; R_0603_1608Metric
TH1: NCP18XH103; R_0603_1608Metric
U3: SY6970QCC; QFN-24_L4.0-W4.0-P0.50-TL-EP2.7; MPN SY6970QCC; LCSC Part C5357542
U4: DW01A; SOT-23-6

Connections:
+3V3: R16.1; also elsewhere on the board
/CELL1_N: C11.1, Q3.1 (S), R22.1, U4.6 (GND); also elsewhere on the board
/CELL1_P: Q2.3 (D), R21.1; also elsewhere on the board
/CH1_V: C12.2, D4.3 (VDD), F1.1; also elsewhere on the board
/RGB_DATA: D4.2 (DIN); also elsewhere on the board
/SCL1: U3.5 (SCL); also elsewhere on the board
/SDA1: U3.6 (SDA); also elsewhere on the board
/charge_chanel_1/BST: C7.2, U3.21 (BST)
/charge_chanel_1/CELL_P_PROT: Q2.2 (S), R23.2, U3.13 (BAT), U3.14 (BAT)
/charge_chanel_1/CHn_V_pre: F1.2, R20.1, R23.1
/charge_chanel_1/REGN: C10.2, R18.1, R19.1, U3.22 (REGN)
/charge_chanel_1/RGB_DOUT: D4.4 (DOUT); also elsewhere on the board
GND: C6.1, C8.2, C9.1, C10.1, C12.1, D4.1 (VSS), Q3.3 (S), R15.1, R17.1, R24.2, TH1.1, U3.8 (OTG), U3.9 (CE), U3.17 (PGND), U3.18 (PGND), U3.24 (DSEL), U3.25 (PGND); also elsewhere on the board
unnamed: C7.1, L1.1, U3.19 (LX), U3.20 (LX)
unnamed: C8.1, L1.2, R20.2, U3.15 (SYS), U3.16 (SYS)
unnamed: D3.2 (A), R16.2
unnamed: D3.1 (K), U3.4 (STAT)
unnamed: Q2.1 (G), R22.2
unnamed: Q3.5 (D), Q3.6 (D), Q3.7 (D), Q3.8 (D)
unnamed: Q3.2 (G), U4.1 (OD)
unnamed: Q3.4 (G), U4.3 (OC)
unnamed: R17.2, U3.10 (ILIM)
unnamed: R15.2, R18.2, TH1.2, U3.11 (NTC)
unnamed: C9.2, U3.23 (PMID)
unnamed: R19.2, U3.12 (~QON)
unnamed: R24.1, U4.2 (CS)
unnamed: C11.2, R21.2, U4.5 (VCC)
VBUS: C6.2, U3.1 (BUS); also elsewhere on the board

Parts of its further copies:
C15: 10uf/25V; C_1206_3216Metric
C16: 47nF; C_0805_2012Metric
C17: 22uF; C_1206_3216Metric
C18: 6.8uF/25V; C_0805_2012Metric
C19: 4.7uF; C_0805_2012Metric
C20, C21: 0.1uF; C_0603_1608Metric
D6: LED; LED_0603_1608Metric
D7: SK6812; LED_SK6812_PLCC4_5.0x5.0mm_P3.2mm
F2: Polyfuse; Fuse_1812_4532Metric
L2: SRP5030CA-2R2M; IND-SMD_L5.5-W5.3; MPN SRP5030CA-2R2M; LCSC Part C2046809
Q4: DMG2305UX; SOT-23
Q5: SI4920DY; SOIC-8_L4.9-W3.9-P1.27-LS6.2-BL; MPN SI4920DY; LCSC Part C3289759
R34: 30.3R; R_0603_1608Metric
R35: 1K; R_0603_1608Metric
R36: 360R; R_0603_1608Metric
R37: 5.24R; R_0603_1608Metric
R38: 100K; R_0603_1608Metric
R39: 0R; R_2010_5025Metric
R40: 100R; R_0603_1608Metric
R41: 100k; R_0603_1608Metric
R42: 0R; R_2010_5025Metric; not fitted
R43: 2K; R_0603_1608Metric
TH2: NCP18XH103; R_0603_1608Metric
U7: SY6970QCC; QFN-24_L4.0-W4.0-P0.50-TL-EP2.7; MPN SY6970QCC; LCSC Part C5357542
U8: DW01A; SOT-23-6

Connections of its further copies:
+3V3: R35.1; also elsewhere on the board
/CELL2_N: C20.1, Q5.1 (S), R41.1, U8.6 (GND); also elsewhere on the board
/CELL2_P: Q4.3 (D), R40.1; also elsewhere on the board
/CH1_V: C21.2, D7.3 (VDD); also elsewhere on the board
/CH2_V: F2.1; also elsewhere on the board
/SCL2: U7.5 (SCL); also elsewhere on the board
/SDA2: U7.6 (SDA); also elsewhere on the board
/charge_chanel_1/RGB_DOUT: D7.2 (DIN); also elsewhere on the board
/charge_chanel_2/BST: C16.2, U7.21 (BST)
/charge_chanel_2/CELL_P_PROT: Q4.2 (S), R42.2, U7.13 (BAT), U7.14 (BAT)
/charge_chanel_2/CHn_V_pre: F2.2, R39.1, R42.1
/charge_chanel_2/REGN: C19.2, R37.1, R38.1, U7.22 (REGN)
/charge_chanel_2/RGB_DOUT: D7.4 (DOUT)
GND: C15.1, C17.2, C18.1, C19.1, C21.1, D7.1 (VSS), Q5.3 (S), R34.1, R36.1, R43.2, TH2.1, U7.8 (OTG), U7.9 (CE), U7.17 (PGND), U7.18 (PGND), U7.24 (DSEL), U7.25 (PGND); also elsewhere on the board
unnamed: C16.1, L2.1, U7.19 (LX), U7.20 (LX)
unnamed: C17.1, L2.2, R39.2, U7.15 (SYS), U7.16 (SYS)
unnamed: D6.2 (A), R35.2
unnamed: D6.1 (K), U7.4 (STAT)
unnamed: Q4.1 (G), R41.2
unnamed: Q5.5 (D), Q5.6 (D), Q5.7 (D), Q5.8 (D)
unnamed: Q5.2 (G), U8.1 (OD)
unnamed: Q5.4 (G), U8.3 (OC)
unnamed: R36.2, U7.10 (ILIM)
unnamed: R34.2, R37.2, TH2.2, U7.11 (NTC)
unnamed: C18.2, U7.23 (PMID)
unnamed: R38.2, U7.12 (~QON)
unnamed: R43.1, U8.2 (CS)
unnamed: C20.2, R40.2, U8.5 (VCC)
VBUS: C15.2, U7.1 (BUS); also elsewhere on the board

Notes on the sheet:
OVER VOLT UNDER VOLT CELL PROTECTION
CELL PROTECTION
0R FOR RAWBAT TURNS OFF SMART POWER
POLARITY PROTECTION
STATUS LED
Battery Thermistor
0C->45C Safe Charging temps
0R FOR SMART POWER REMOVE FOR RAWBAT
OVER CURENT FUSE
FUSE
Cell Protection
DIODE BASED CELL POLARITY PROTECTION
I2C 5A SMART CHARGER
CELL BUCK CHARGER
LED FOR CELL STATUS CHARGIN, ERROR, CHARGED
Resetable Poly Fuse

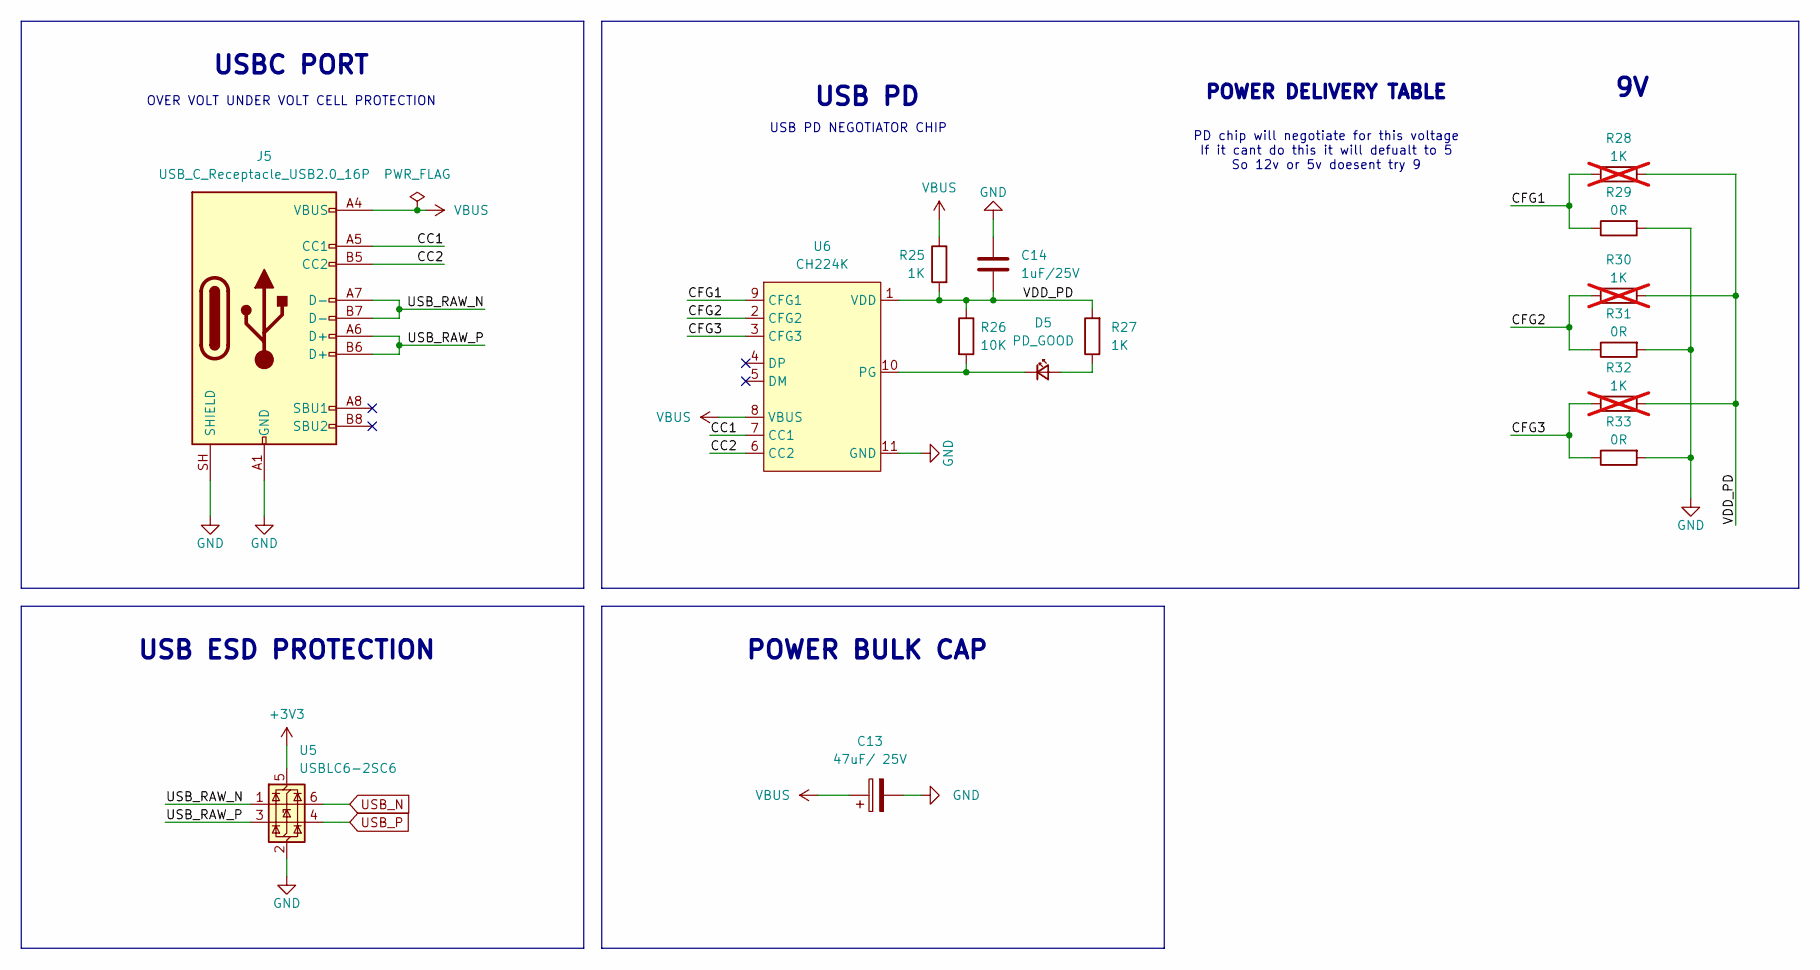
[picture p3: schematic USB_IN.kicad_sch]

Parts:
C13: 47uF/ 25V; CP_Elec_6.3x5.4
C14: 1uF/25V; C_0603_1608Metric
D5: PD_GOOD; LED_0603_1608Metric_Green
J5: USB_C_Receptacle_USB2.0_16P; USB_C_Receptacle_GCT_USB4105-xx-A_16P_TopMnt_Horizontal
R25: 1K; R_0805_2012Metric
R26: 10K; R_0603_1608Metric
R27: 1K; R_0603_1608Metric
R28, R30, R32: 1K; R_0805_2012Metric; not fitted
R29, R31, R33: 0R; R_0805_2012Metric
U5: USBLC6-2SC6; SOT-23-6
U6: CH224K; ESSOP-10_L4.9-W3.9-P1.0-LS6.0-TL-EP; MPN CH224K; LCSC Part C970725

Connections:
+3V3: U5.5 (VBUS); also elsewhere on the board
/USB_IN/CC1: J5.A5 (CC1), U6.7 (CC1)
/USB_IN/CC2: J5.B5 (CC2), U6.6 (CC2)
/USB_IN/CFG1: R28.2, R29.1, U6.9 (CFG1)
/USB_IN/CFG2: R30.2, R31.1, U6.2 (CFG2)
/USB_IN/CFG3: R32.2, R33.1, U6.3 (CFG3)
/USB_IN/USB_RAW_N: J5.A7 (D-), J5.B7 (D-), U5.1 (I/O1)
/USB_IN/USB_RAW_P: J5.A6 (D+), J5.B6 (D+), U5.3 (I/O2)
/USB_IN/VDD_PD: C14.2, R25.2, R26.1, R27.2, R28.1, R30.1, R32.1, U6.1 (VDD)
GND: C13.2, C14.1, J5.A1 (GND), J5.A12 (GND), J5.B1 (GND), J5.B12 (GND), J5.SH (SHIELD), R29.2, R31.2, R33.2, U5.2 (GND), U6.11 (GND); also elsewhere on the board
unnamed: D5.2 (A), R27.1
unnamed: D5.1 (K), R26.2, U6.10 (PG)
USB_N: U5.6 (I/O1); also elsewhere on the board
USB_P: U5.4 (I/O2); also elsewhere on the board
VBUS: C13.1, J5.A4 (VBUS), J5.A9 (VBUS), J5.B4 (VBUS), J5.B9 (VBUS), R25.1, U6.8 (VBUS); also elsewhere on the board

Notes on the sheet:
OVER VOLT UNDER VOLT CELL PROTECTION
USB ESD PROTECTION
USBC PORT
USB PD
POWER BULK CAP
PD chip will negotiate for this voltage If it cant do this it will defualt to 5 So 12v or 5v doesent try 9
USB PD NEGOTIATOR CHIP
POWER DELIVERY TABLE

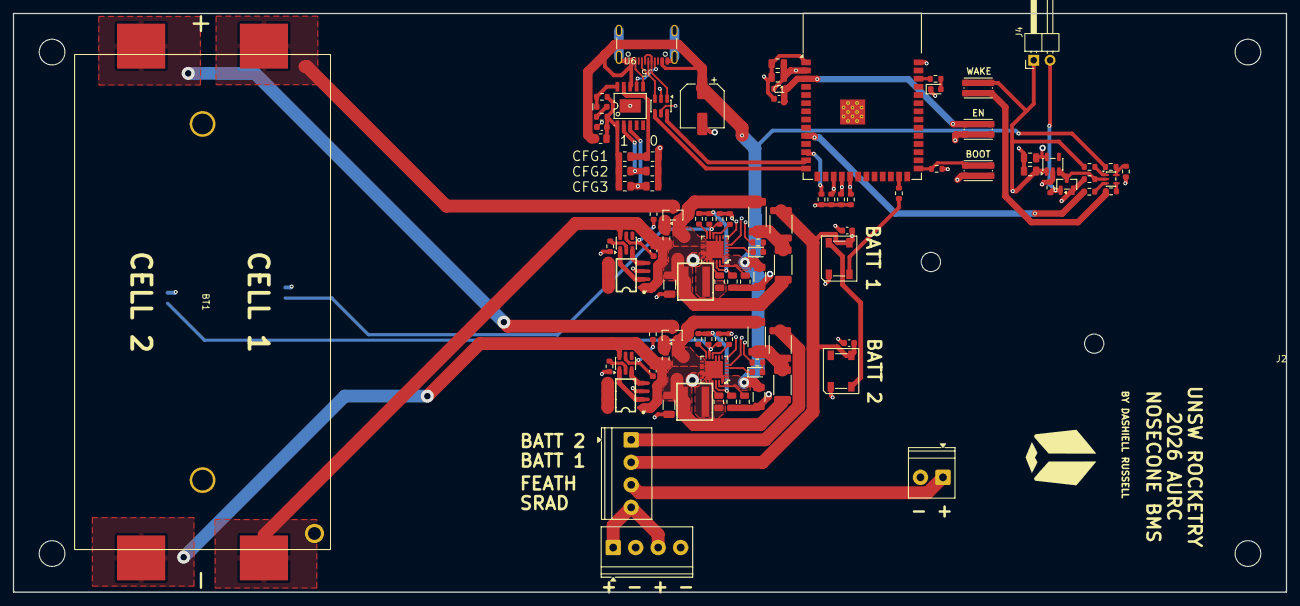
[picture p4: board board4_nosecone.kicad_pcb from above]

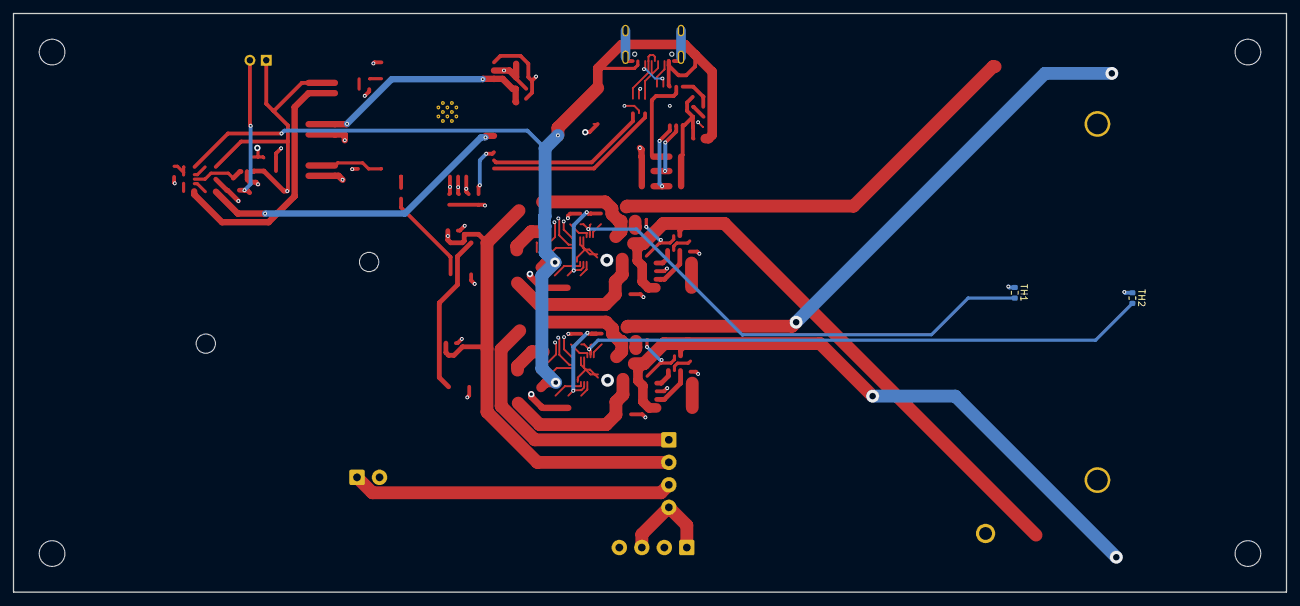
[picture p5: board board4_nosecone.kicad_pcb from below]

Board: 4 copper layers, 198.0 x 90.0 mm, 100 parts (2 on the bottom side), 78 nets.

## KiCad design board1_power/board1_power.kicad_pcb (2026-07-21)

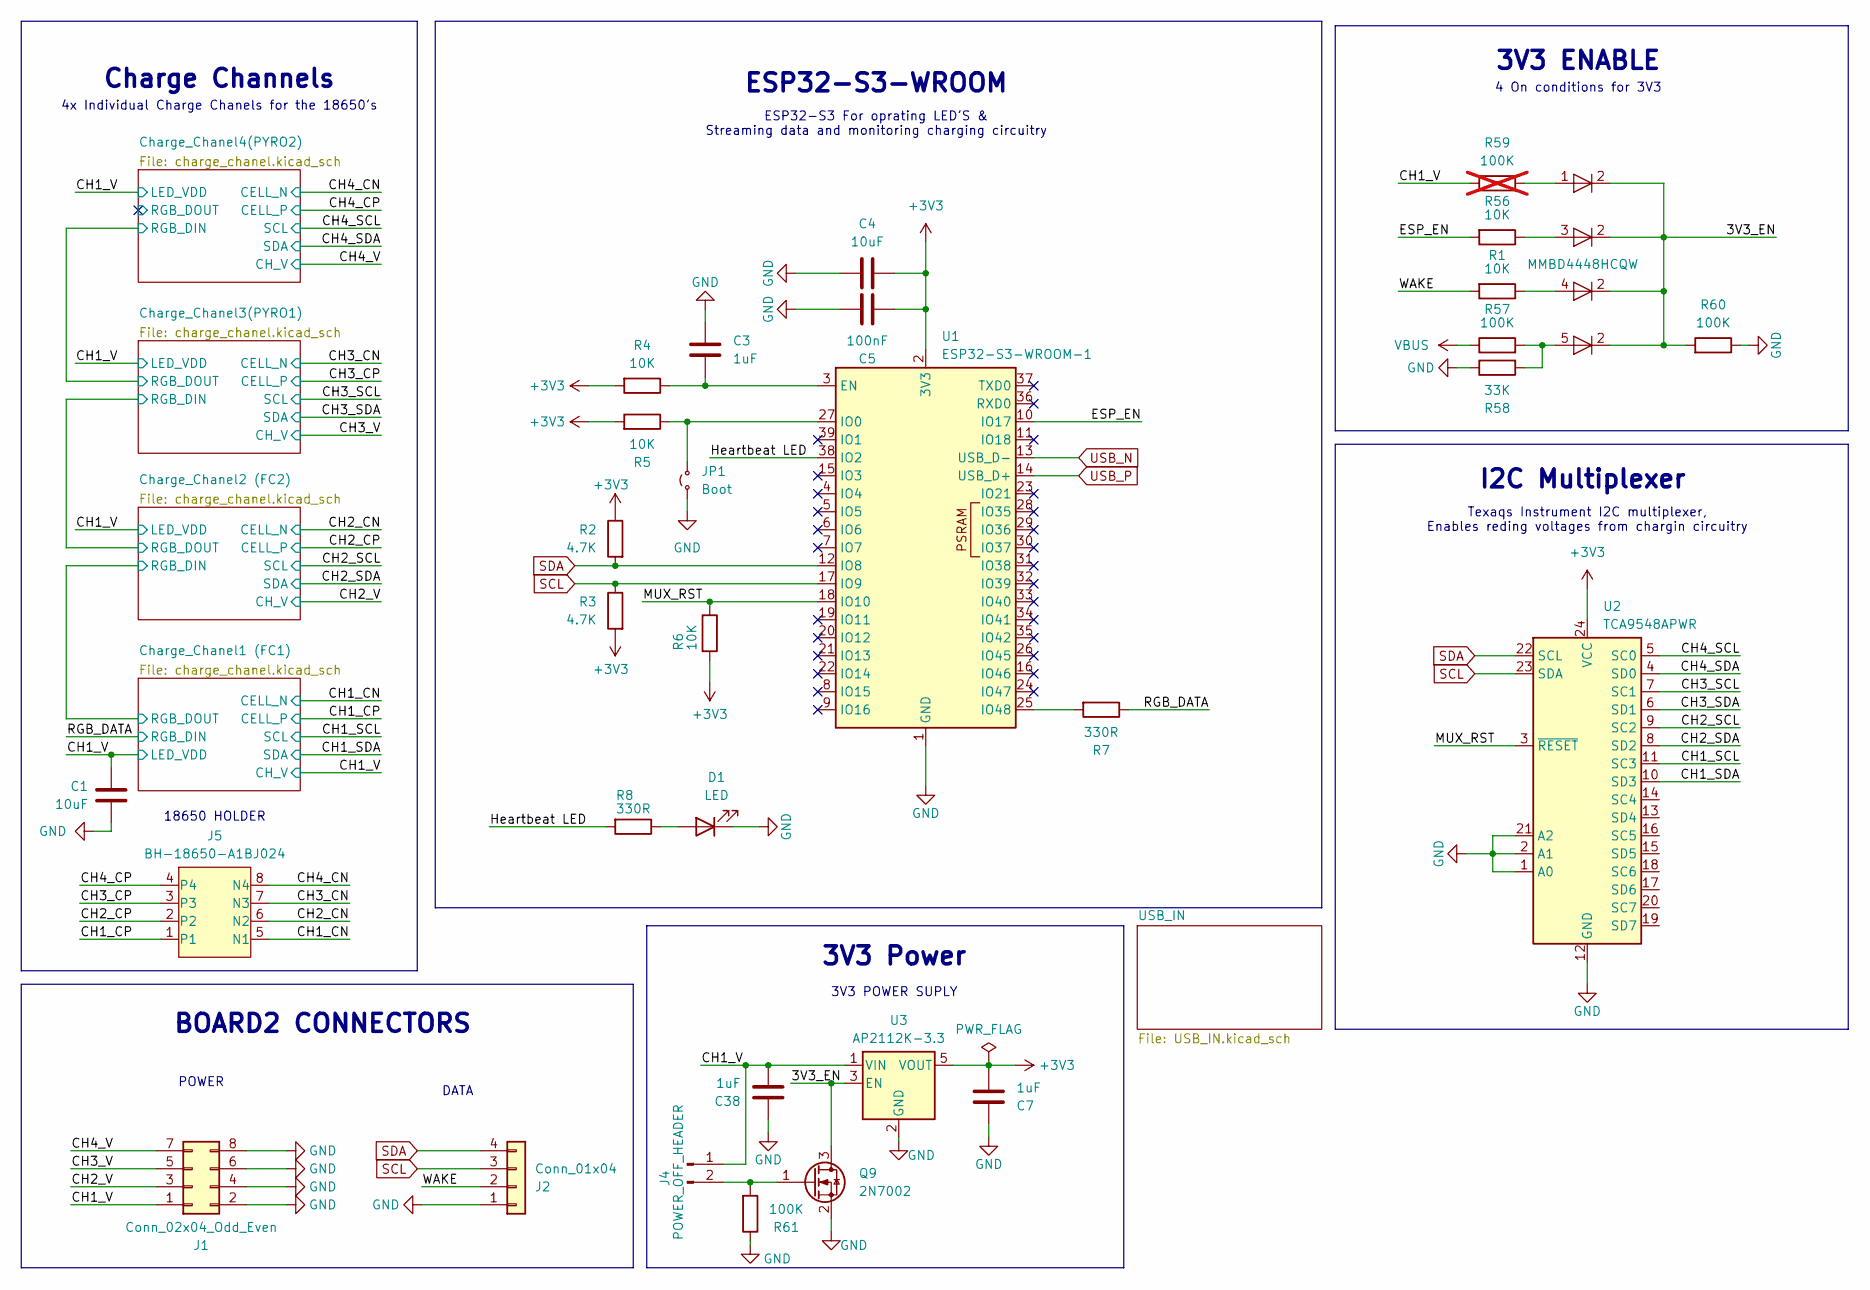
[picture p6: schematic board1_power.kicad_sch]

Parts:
C1, C4: 10uF; C_0805_2012Metric
C3: 1uF; C_0603_1608Metric
C5: 100nF; C_0805_2012Metric
C7, C38: 1uF; C_0805_2012Metric
D1: LED; LED_0603_1608Metric
D12: MMBD4448HCQW; SOT-353_SC-70-5
J1: Conn_02x04_Odd_Even; PinSocket_2x04_P2.54mm_Horizontal
J2: Conn_01x04; PinSocket_1x04_P2.54mm_Horizontal
J4: POWER_OFF_HEADER; PinHeader_1x02_P2.54mm_Horizontal
J5: BH-18650-A1BJ024
JP1: Boot; TestPoint_2Pads_Pitch2.54mm_Drill0.8mm
Q9: 2N7002; SOT-23
R1, R4, R5, R6, R56: 10K; R_0603_1608Metric
R2, R3: 4.7K; R_0603_1608Metric
R7, R8: 330R; R_0603_1608Metric
R57, R60, R61: 100K; R_0603_1608Metric
R58: 33K; R_0603_1608Metric
R59: 100K; R_0603_1608Metric; not fitted
U1: ESP32-S3-WROOM-1
U2: TCA9548APWR; TSSOP-24_4.4x7.8mm_P0.65mm
U3: AP2112K-3.3; SOT-23-5

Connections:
+3V3: C4.1, C5.1, C7.1, R2.1, R3.2, R4.2, R5.2, R6.2, U1.2 (3V3), U2.24 (VCC), U3.5 (VOUT); also elsewhere on the board
/3V3_EN: D12.2 (K), Q9.3 (D), R60.2, U3.3 (EN)
/CH1_CN: J5.5 (N1); also elsewhere on the board
/CH1_CP: J5.1; also elsewhere on the board
/CH1_SCL: U2.11 (SC3); also elsewhere on the board
/CH1_SDA: U2.10 (SD3); also elsewhere on the board
/CH1_V: C1.1, C38.1, J1.1, J4.1, R59.1, U3.1 (VIN); also elsewhere on the board
/CH2_CN: J5.6 (N2); also elsewhere on the board
/CH2_CP: J5.2; also elsewhere on the board
/CH2_SCL: U2.9 (SC2); also elsewhere on the board
/CH2_SDA: U2.8 (SD2); also elsewhere on the board
/CH2_V: J1.3; also elsewhere on the board
/CH3_CN: J5.7 (N3); also elsewhere on the board
/CH3_CP: J5.3; also elsewhere on the board
/CH3_SCL: U2.7 (SC1); also elsewhere on the board
/CH3_SDA: U2.6 (SD1); also elsewhere on the board
/CH3_V: J1.5; also elsewhere on the board
/CH4_CN: J5.8 (N4); also elsewhere on the board
/CH4_CP: J5.4; also elsewhere on the board
/CH4_SCL: U2.5 (SC0); also elsewhere on the board
/CH4_SDA: U2.4 (SD0); also elsewhere on the board
/CH4_V: J1.7; also elsewhere on the board
/ESP_EN: R56.2, U1.10 (IO17)
/Heartbeat LED: R8.2, U1.38 (IO2)
/MUX_RST: R6.1, U1.18 (IO10), U2.3 (~RESET)
/RGB_DATA: R7.1; also elsewhere on the board
/WAKE: J2.2, R1.2
GND: C1.2, C3.1, C4.2, C5.2, C7.2, C38.2, D1.1 (K), J1.2, J1.4, J1.6, J1.8, J2.1, JP1.1 (A), Q9.2 (S), R58.1, R60.1, R61.1, U1.1 (GND), U1.40 (GND), U1.41 (GND), U2.1 (A0), U2.2 (A1), U2.12 (GND), U2.21 (A2), U3.2 (GND); also elsewhere on the board
unnamed: D1.2 (A), R8.1
unnamed: D12.1 (A), R59.2
unnamed: D12.3 (A), R56.1
unnamed: D12.4 (A), R1.1
unnamed: D12.5 (A), R57.2, R58.2
unnamed: J4.2, Q9.1 (G), R61.2
unnamed: JP1.2 (B), R5.1, U1.27 (IO0)
unnamed: C3.2, R4.1, U1.3 (EN)
unnamed: R7.2, U1.25 (IO48)
SCL: J2.3, R3.1, U1.17 (IO9), U2.23 (SDA)
SDA: J2.4, R2.2, U1.12 (IO8), U2.22 (SCL)
USB_N: U1.13 (USB_D-); also elsewhere on the board
USB_P: U1.14 (USB_D+); also elsewhere on the board
VBUS: R57.1; also elsewhere on the board

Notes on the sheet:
ESP32-S3-WROOM
4x Individual Charge Chanels for the 18650's
Texaqs Instrument I2C multiplexer, Enables reding voltages from chargin circuitry
3V3 ENABLE
4 On conditions for 3V3
ESP32-S3 For oprating LED'S & Streaming data and monitoring charging circuitry
18650 HOLDER
BOARD2 CONNECTORS
3V3 POWER SUPLY
DATA
3V3 Power
Charge Channels
I2C Multiplexer
POWER

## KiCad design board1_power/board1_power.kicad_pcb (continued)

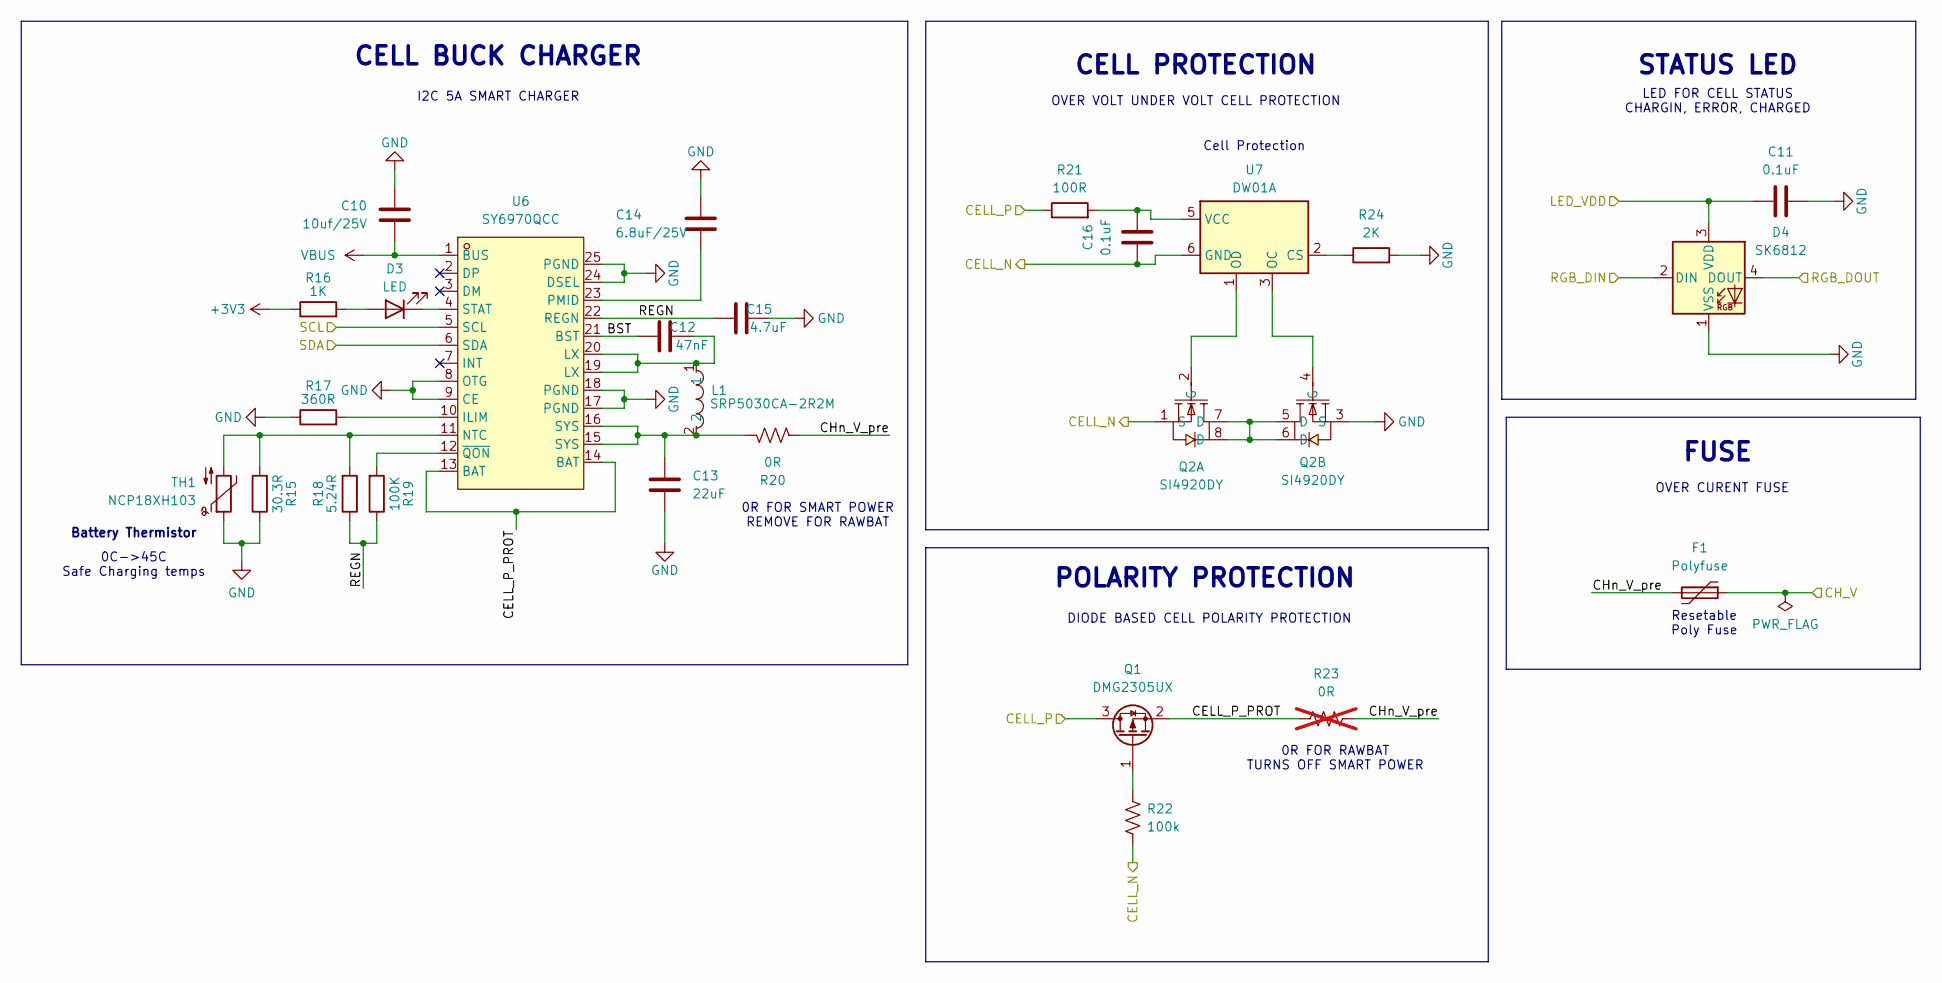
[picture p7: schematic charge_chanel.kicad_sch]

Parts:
C10: 10uf/25V; C_1206_3216Metric
C11, C16: 0.1uF; C_0603_1608Metric
C12: 47nF; C_0805_2012Metric
C13: 22uF; C_1206_3216Metric
C14: 6.8uF/25V; C_0805_2012Metric
C15: 4.7uF; C_0805_2012Metric
D3: LED; LED_0603_1608Metric
D4: SK6812; LED_SK6812_PLCC4_5.0x5.0mm_P3.2mm
F1: Polyfuse; Fuse_1812_4532Metric
L1: SRP5030CA-2R2M; IND-SMD_L5.5-W5.3; MPN SRP5030CA-2R2M; LCSC Part C2046809
Q1: DMG2305UX; SOT-23
Q2: SI4920DY; SOIC-8_L4.9-W3.9-P1.27-LS6.2-BL; MPN SI4920DY; LCSC Part C3289759
R15: 30.3R; R_0603_1608Metric
R16: 1K; R_0603_1608Metric
R17: 360R; R_0603_1608Metric
R18: 5.24R; R_0603_1608Metric
R19: 100K; R_0603_1608Metric
R20: 0R; R_2010_5025Metric
R21: 100R; R_0603_1608Metric
R22: 100k; R_0603_1608Metric
R23: 0R; R_2010_5025Metric; not fitted
R24: 2K; R_0603_1608Metric
TH1: NCP18XH103; R_0603_1608Metric
U6: SY6970QCC; QFN-24_L4.0-W4.0-P0.50-TL-EP2.7; MPN SY6970QCC; LCSC Part C5357542
U7: DW01A; SOT-23-6

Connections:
+3V3: R16.1; also elsewhere on the board
/CH1_CN: C16.1, Q2.1 (S), R22.1, U7.6 (GND); also elsewhere on the board
/CH1_CP: Q1.3 (D), R21.1; also elsewhere on the board
/CH1_SCL: U6.5 (SCL); also elsewhere on the board
/CH1_SDA: U6.6 (SDA); also elsewhere on the board
/CH1_V: C11.2, D4.3 (VDD), F1.1; also elsewhere on the board
/Charge_Chanel1 (FC1)/BST: C12.2, U6.21 (BST)
/Charge_Chanel1 (FC1)/CELL_P_PROT: Q1.2 (S), R23.2, U6.13 (BAT), U6.14 (BAT)
/Charge_Chanel1 (FC1)/CHn_V_pre: F1.2, R20.1, R23.1
/Charge_Chanel1 (FC1)/REGN: C15.2, R18.1, R19.1, U6.22 (REGN)
/Charge_Chanel1 (FC1)/RGB_DOUT: D4.4 (DOUT); also elsewhere on the board
/RGB_DATA: D4.2 (DIN); also elsewhere on the board
GND: C10.1, C11.1, C13.2, C14.1, C15.1, D4.1 (VSS), Q2.3 (S), R15.1, R17.1, R24.2, TH1.1, U6.8 (OTG), U6.9 (CE), U6.17 (PGND), U6.18 (PGND), U6.24 (DSEL), U6.25 (PGND); also elsewhere on the board
unnamed: C12.1, L1.1, U6.19 (LX), U6.20 (LX)
unnamed: C13.1, L1.2, R20.2, U6.15 (SYS), U6.16 (SYS)
unnamed: D3.2 (A), R16.2
unnamed: D3.1 (K), U6.4 (STAT)
unnamed: Q1.1 (G), R22.2
unnamed: Q2.5 (D), Q2.6 (D), Q2.7 (D), Q2.8 (D)
unnamed: Q2.2 (G), U7.1 (OD)
unnamed: Q2.4 (G), U7.3 (OC)
unnamed: R17.2, U6.10 (ILIM)
unnamed: R15.2, R18.2, TH1.2, U6.11 (NTC)
unnamed: C14.2, U6.23 (PMID)
unnamed: R19.2, U6.12 (~QON)
unnamed: R24.1, U7.2 (CS)
unnamed: C16.2, R21.2, U7.5 (VCC)
VBUS: C10.2, U6.1 (BUS); also elsewhere on the board

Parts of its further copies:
C17, C24, C31: 10uf/25V; C_1206_3216Metric
C18, C23, C25, C30, C32, C37: 0.1uF; C_0603_1608Metric
C19, C26, C33: 47nF; C_0805_2012Metric
C20, C27, C34: 22uF; C_1206_3216Metric
C21, C28, C35: 6.8uF/25V; C_0805_2012Metric
C22, C29, C36: 4.7uF; C_0805_2012Metric
D5, D7, D9: LED; LED_0603_1608Metric
D6, D8, D10: SK6812; LED_SK6812_PLCC4_5.0x5.0mm_P3.2mm
F2, F3, F4: Polyfuse; Fuse_1812_4532Metric
L2, L3, L4: SRP5030CA-2R2M; IND-SMD_L5.5-W5.3; MPN SRP5030CA-2R2M; LCSC Part C2046809
Q3, Q5, Q7: DMG2305UX; SOT-23
Q4, Q6, Q8: SI4920DY; SOIC-8_L4.9-W3.9-P1.27-LS6.2-BL; MPN SI4920DY; LCSC Part C3289759
R25, R35, R45: 30.3R; R_0603_1608Metric
R26, R36, R46: 1K; R_0603_1608Metric
R27, R37, R47: 360R; R_0603_1608Metric
R28, R38, R48: 5.24R; R_0603_1608Metric
R29, R39, R49: 100K; R_0603_1608Metric
R30, R40, R50: 0R; R_2010_5025Metric
R31, R41, R51: 100R; R_0603_1608Metric
R32, R42, R52: 100k; R_0603_1608Metric
R33, R43, R53: 0R; R_2010_5025Metric; not fitted
R34, R44, R54: 2K; R_0603_1608Metric
TH2, TH3, TH4: NCP18XH103; R_0603_1608Metric
U8, U10, U12: SY6970QCC; QFN-24_L4.0-W4.0-P0.50-TL-EP2.7; MPN SY6970QCC; LCSC Part C5357542
U9, U11, U13: DW01A; SOT-23-6

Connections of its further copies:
+3V3: R26.1, R36.1, R46.1; also elsewhere on the board
/CH1_V: C18.2, C25.2, C32.2, D6.3 (VDD), D8.3 (VDD), D10.3 (VDD); also elsewhere on the board
/CH2_CN: C23.1, Q4.1 (S), R32.1, U9.6 (GND); also elsewhere on the board
/CH2_CP: Q3.3 (D), R31.1; also elsewhere on the board
/CH2_SCL: U8.5 (SCL); also elsewhere on the board
/CH2_SDA: U8.6 (SDA); also elsewhere on the board
/CH2_V: F2.1; also elsewhere on the board
/CH3_CN: C30.1, Q6.1 (S), R42.1, U11.6 (GND); also elsewhere on the board
/CH3_CP: Q5.3 (D), R41.1; also elsewhere on the board
/CH3_SCL: U10.5 (SCL); also elsewhere on the board
/CH3_SDA: U10.6 (SDA); also elsewhere on the board
/CH3_V: F3.1; also elsewhere on the board
/CH4_CN: C37.1, Q8.1 (S), R52.1, U13.6 (GND); also elsewhere on the board
/CH4_CP: Q7.3 (D), R51.1; also elsewhere on the board
/CH4_SCL: U12.5 (SCL); also elsewhere on the board
/CH4_SDA: U12.6 (SDA); also elsewhere on the board
/CH4_V: F4.1; also elsewhere on the board
/Charge_Chanel1 (FC1)/RGB_DOUT: D6.2 (DIN); also elsewhere on the board
/Charge_Chanel2 (FC2)/BST: C19.2, U8.21 (BST)
/Charge_Chanel2 (FC2)/CELL_P_PROT: Q3.2 (S), R33.2, U8.13 (BAT), U8.14 (BAT)
/Charge_Chanel2 (FC2)/CHn_V_pre: F2.2, R30.1, R33.1
/Charge_Chanel2 (FC2)/REGN: C22.2, R28.1, R29.1, U8.22 (REGN)
/Charge_Chanel2 (FC2)/RGB_DOUT: D6.4 (DOUT), D8.2 (DIN)
/Charge_Chanel3(PYRO1)/BST: C26.2, U10.21 (BST)
/Charge_Chanel3(PYRO1)/CELL_P_PROT: Q5.2 (S), R43.2, U10.13 (BAT), U10.14 (BAT)
/Charge_Chanel3(PYRO1)/CHn_V_pre: F3.2, R40.1, R43.1
/Charge_Chanel3(PYRO1)/REGN: C29.2, R38.1, R39.1, U10.22 (REGN)
/Charge_Chanel3(PYRO1)/RGB_DOUT: D8.4 (DOUT), D10.2 (DIN)
/Charge_Chanel4(PYRO2)/BST: C33.2, U12.21 (BST)
/Charge_Chanel4(PYRO2)/CELL_P_PROT: Q7.2 (S), R53.2, U12.13 (BAT), U12.14 (BAT)
/Charge_Chanel4(PYRO2)/CHn_V_pre: F4.2, R50.1, R53.1
/Charge_Chanel4(PYRO2)/REGN: C36.2, R48.1, R49.1, U12.22 (REGN)
/Charge_Chanel4(PYRO2)/RGB_DOUT: D10.4 (DOUT)
GND: C17.1, C18.1, C20.2, C21.1, C22.1, C24.1, C25.1, C27.2, C28.1, C29.1, C31.1, C32.1, C34.2, C35.1, C36.1, D6.1 (VSS), D8.1 (VSS), D10.1 (VSS), Q4.3 (S), Q6.3 (S), Q8.3 (S), R25.1, R27.1, R34.2, R35.1, R37.1, R44.2, R45.1, R47.1, R54.2, TH2.1, TH3.1, TH4.1, U8.8 (OTG), U8.9 (CE), U8.17 (PGND), U8.18 (PGND), U8.24 (DSEL), U8.25 (PGND), U10.8 (OTG), U10.9 (CE), U10.17 (PGND), U10.18 (PGND), U10.24 (DSEL), U10.25 (PGND), U12.8 (OTG), U12.9 (CE), U12.17 (PGND), U12.18 (PGND), U12.24 (DSEL), U12.25 (PGND); also elsewhere on the board
unnamed: C19.1, L2.1, U8.19 (LX), U8.20 (LX)
unnamed: C20.1, L2.2, R30.2, U8.15 (SYS), U8.16 (SYS)
unnamed: C26.1, L3.1, U10.19 (LX), U10.20 (LX)
unnamed: C27.1, L3.2, R40.2, U10.15 (SYS), U10.16 (SYS)
unnamed: C33.1, L4.1, U12.19 (LX), U12.20 (LX)
unnamed: C34.1, L4.2, R50.2, U12.15 (SYS), U12.16 (SYS)
unnamed: D5.2 (A), R26.2
unnamed: D5.1 (K), U8.4 (STAT)
unnamed: D7.2 (A), R36.2
unnamed: D7.1 (K), U10.4 (STAT)
unnamed: D9.2 (A), R46.2
unnamed: D9.1 (K), U12.4 (STAT)
unnamed: Q3.1 (G), R32.2
unnamed: Q4.5 (D), Q4.6 (D), Q4.7 (D), Q4.8 (D)
unnamed: Q4.2 (G), U9.1 (OD)
unnamed: Q4.4 (G), U9.3 (OC)
unnamed: Q5.1 (G), R42.2
unnamed: Q6.5 (D), Q6.6 (D), Q6.7 (D), Q6.8 (D)
unnamed: Q6.2 (G), U11.1 (OD)
unnamed: Q6.4 (G), U11.3 (OC)
unnamed: Q7.1 (G), R52.2
unnamed: Q8.5 (D), Q8.6 (D), Q8.7 (D), Q8.8 (D)
unnamed: Q8.2 (G), U13.1 (OD)
unnamed: Q8.4 (G), U13.3 (OC)
unnamed: R27.2, U8.10 (ILIM)
unnamed: R25.2, R28.2, TH2.2, U8.11 (NTC)
unnamed: C21.2, U8.23 (PMID)
unnamed: R29.2, U8.12 (~QON)
unnamed: R34.1, U9.2 (CS)
unnamed: C23.2, R31.2, U9.5 (VCC)
unnamed: R37.2, U10.10 (ILIM)
unnamed: R35.2, R38.2, TH3.2, U10.11 (NTC)
unnamed: C28.2, U10.23 (PMID)
unnamed: R39.2, U10.12 (~QON)
unnamed: R44.1, U11.2 (CS)
unnamed: C30.2, R41.2, U11.5 (VCC)
unnamed: R47.2, U12.10 (ILIM)
unnamed: R45.2, R48.2, TH4.2, U12.11 (NTC)
unnamed: C35.2, U12.23 (PMID)
unnamed: R49.2, U12.12 (~QON)
unnamed: R54.1, U13.2 (CS)
unnamed: C37.2, R51.2, U13.5 (VCC)
VBUS: C17.2, C24.2, C31.2, U8.1 (BUS), U10.1 (BUS), U12.1 (BUS); also elsewhere on the board

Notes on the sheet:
OVER VOLT UNDER VOLT CELL PROTECTION
CELL PROTECTION
0R FOR RAWBAT TURNS OFF SMART POWER
POLARITY PROTECTION
STATUS LED
Battery Thermistor
0C->45C Safe Charging temps
0R FOR SMART POWER REMOVE FOR RAWBAT
OVER CURENT FUSE
FUSE
Cell Protection
DIODE BASED CELL POLARITY PROTECTION
I2C 5A SMART CHARGER
CELL BUCK CHARGER
LED FOR CELL STATUS CHARGIN, ERROR, CHARGED
Resetable Poly Fuse

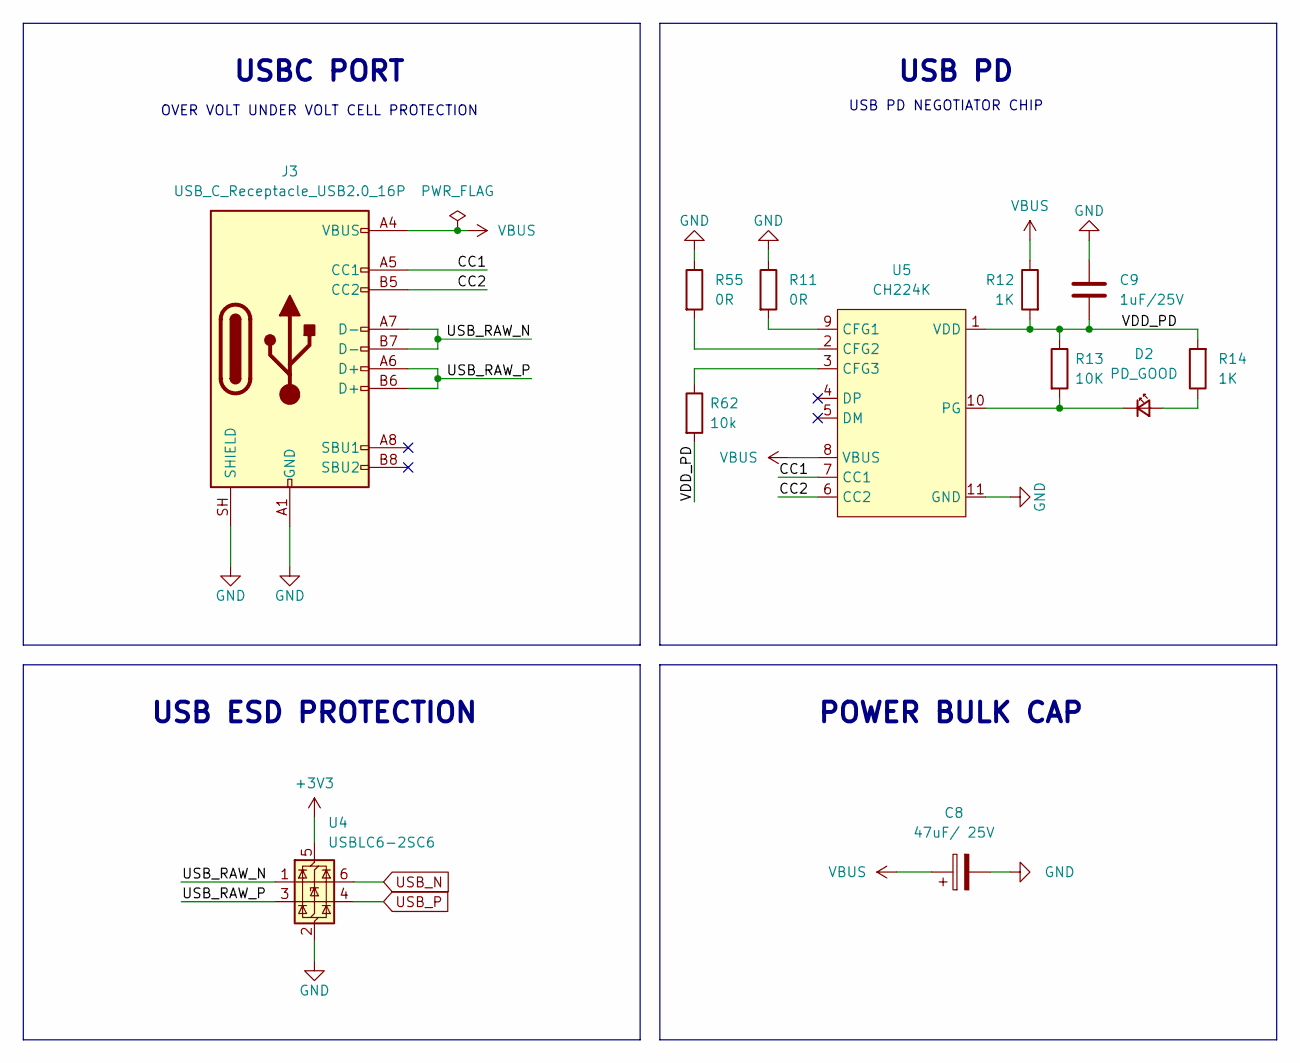
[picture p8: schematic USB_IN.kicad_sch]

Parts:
C8: 47uF/ 25V; CP_Elec_6.3x5.4
C9: 1uF/25V; C_0603_1608Metric
D2: PD_GOOD; LED_0603_1608Metric_Green
J3: USB_C_Receptacle_USB2.0_16P; USB_C_Receptacle_GCT_USB4105-xx-A_16P_TopMnt_Horizontal
R11, R55: 0R; R_0805_2012Metric
R12: 1K; R_0805_2012Metric
R13: 10K; R_0603_1608Metric
R14: 1K; R_0603_1608Metric
R62: 10k; R_0805_2012Metric
U4: USBLC6-2SC6; SOT-23-6
U5: CH224K; ESSOP-10_L4.9-W3.9-P1.0-LS6.0-TL-EP; MPN CH224K; LCSC Part C970725

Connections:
+3V3: U4.5 (VBUS); also elsewhere on the board
/USB_IN/CC1: J3.A5 (CC1), U5.7 (CC1)
/USB_IN/CC2: J3.B5 (CC2), U5.6 (CC2)
/USB_IN/USB_RAW_N: J3.A7 (D-), J3.B7 (D-), U4.1 (I/O1)
/USB_IN/USB_RAW_P: J3.A6 (D+), J3.B6 (D+), U4.3 (I/O2)
/USB_IN/VDD_PD: C9.2, R12.2, R13.1, R14.2, R62.2, U5.1 (VDD)
GND: C8.2, C9.1, J3.A1 (GND), J3.A12 (GND), J3.B1 (GND), J3.B12 (GND), J3.SH (SHIELD), R11.1, R55.1, U4.2 (GND), U5.11 (GND); also elsewhere on the board
unnamed: D2.2 (A), R14.1
unnamed: D2.1 (K), R13.2, U5.10 (PG)
unnamed: R11.2, U5.9 (CFG1)
unnamed: R55.2, U5.2 (CFG2)
unnamed: R62.1, U5.3 (CFG3)
USB_N: U4.6 (I/O1); also elsewhere on the board
USB_P: U4.4 (I/O2); also elsewhere on the board
VBUS: C8.1, J3.A4 (VBUS), J3.A9 (VBUS), J3.B4 (VBUS), J3.B9 (VBUS), R12.1, U5.8 (VBUS); also elsewhere on the board

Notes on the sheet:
OVER VOLT UNDER VOLT CELL PROTECTION
USB ESD PROTECTION
USBC PORT
USB PD
POWER BULK CAP
USB PD NEGOTIATOR CHIP

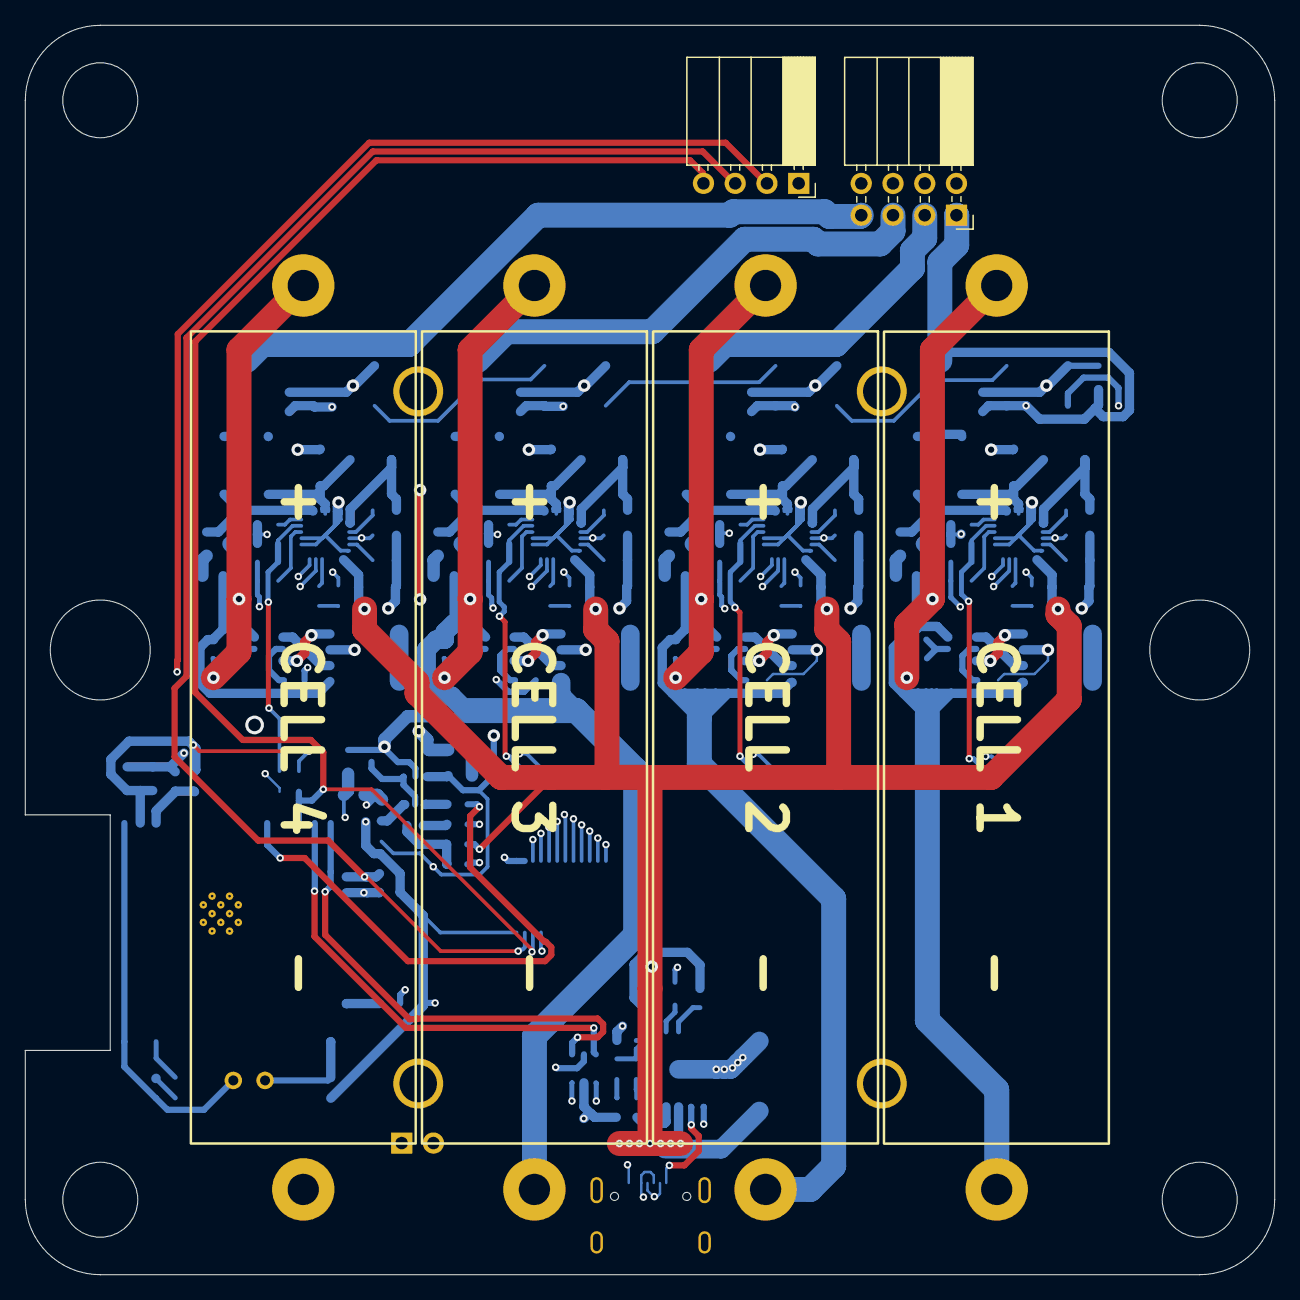
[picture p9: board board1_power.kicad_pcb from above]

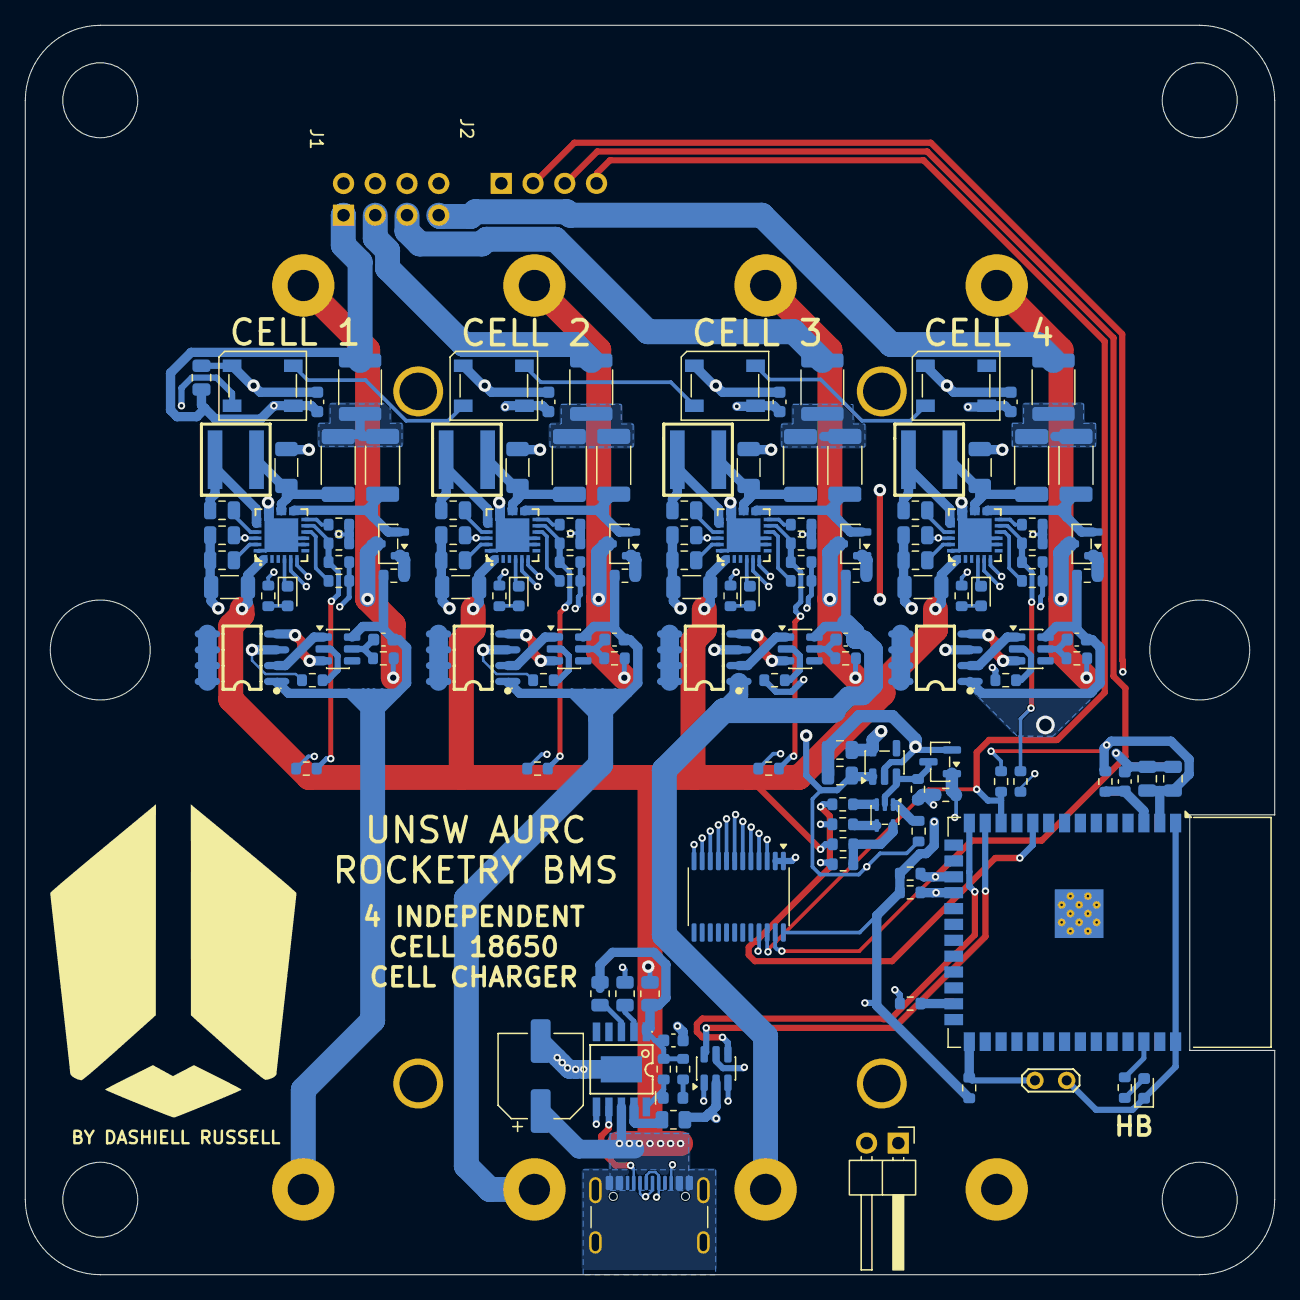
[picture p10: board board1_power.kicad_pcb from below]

Board: 4 copper layers, 100.0 x 100.0 mm, 147 parts (144 on the bottom side), 127 nets.

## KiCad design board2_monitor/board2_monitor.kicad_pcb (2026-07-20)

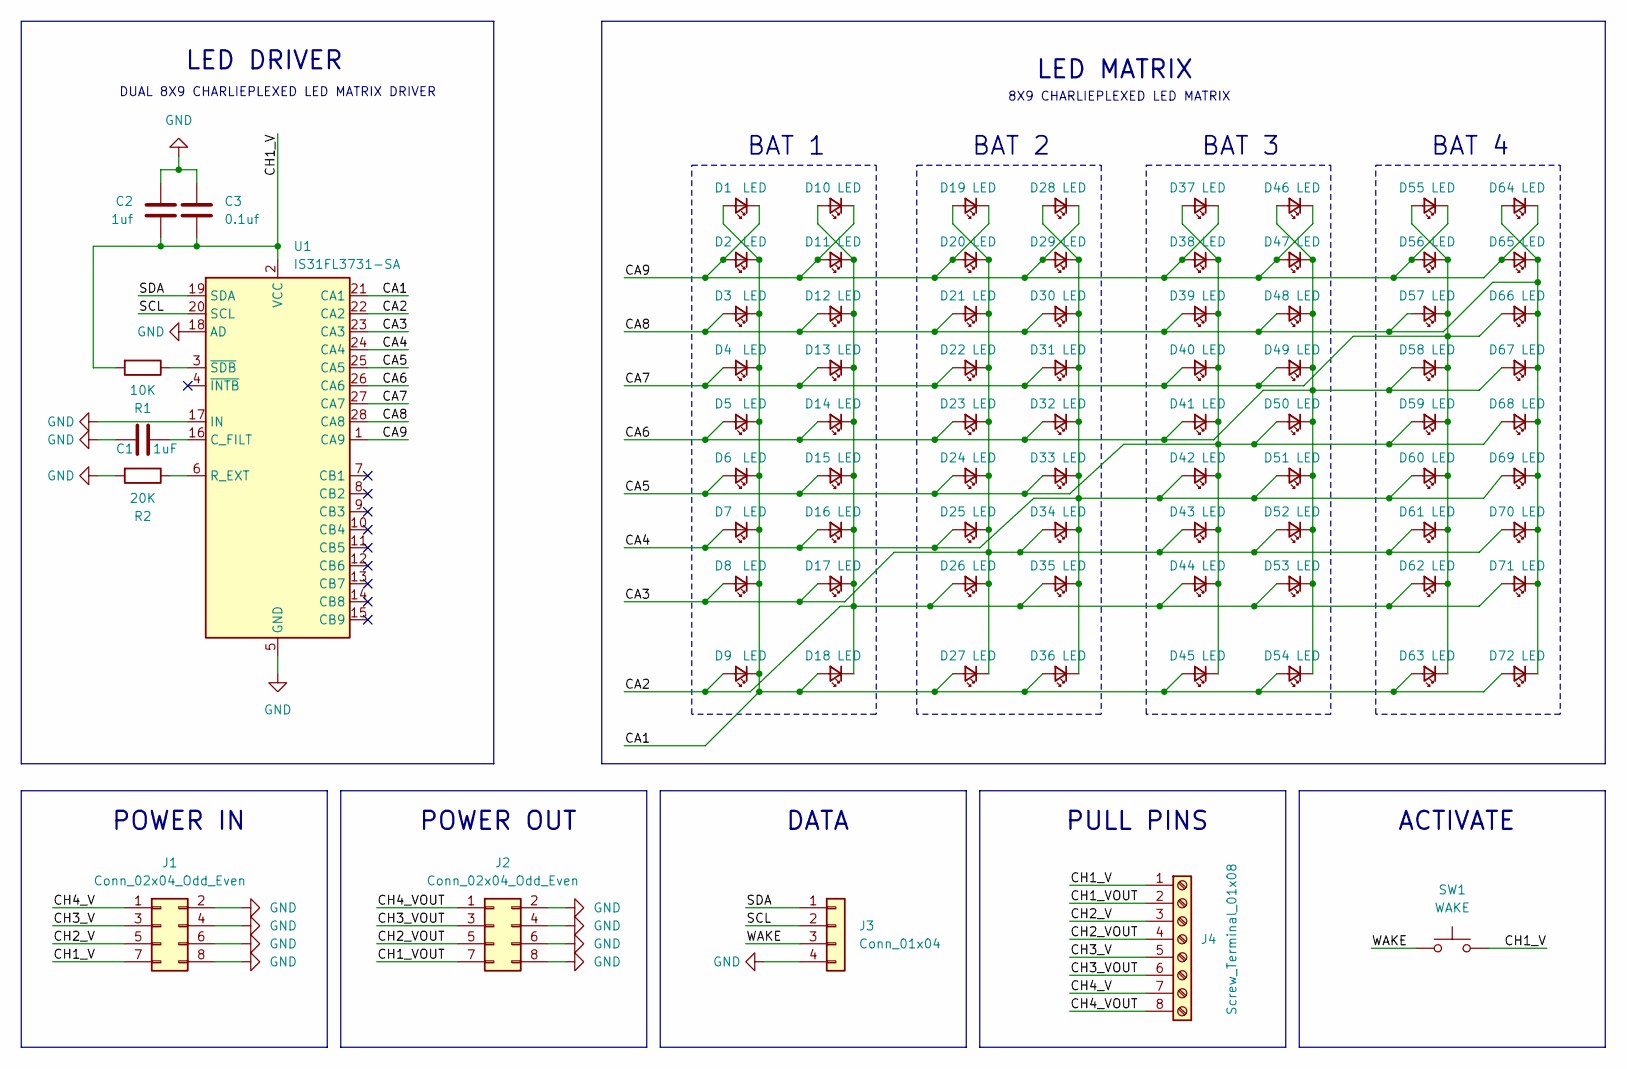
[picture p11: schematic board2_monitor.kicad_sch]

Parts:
C1: 1uF; C_0805_2012Metric
C2: 1uf; C_0805_2012Metric
C3: 0.1uf; C_0805_2012Metric
D1, D2, D3, D4, D5, D6, D7, D8, D9, D10, D11, D12, D13, D14, D15, D16, D17, D18, D19, D20, D21, D22, D23, D24, D25, D26, D27, D28, D29, D30, D31, D32, D33, D34, D35, D36, D37, D38, D39, D40, D41, D42, D43, D44, D45, D46, D47, D48, D49, D50, D51, D52, D53, D54, D55, D56, D57, D58, D59, D60, D61, D62, D63, D64, D65, D66, D67, D68, D69, D70, D71, D72: LED; LED_0603_1608Metric
J1, J2: Conn_02x04_Odd_Even; PinHeader_2x04_P2.54mm_Vertical
J3: Conn_01x04; PinHeader_1x04_P2.54mm_Vertical
J4: Screw_Terminal_01x08; TerminalBlock_Phoenix_PT-1,5-8-3.5-H_1x08_P3.50mm_Horizontal
R1: 10K; R_0805_2012Metric
R2: 20K; R_0805_2012Metric
SW1: WAKE; SW_Push_1P1T_NO_CK_KMR2
U1: IS31FL3731-SA; SSOP-28_5.3x10.2mm_P0.65mm

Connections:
/CA1: D1.2 (A), D2.1 (K), D3.1 (K), D4.1 (K), D5.1 (K), D6.1 (K), D7.1 (K), D8.1 (K), D9.1 (K), D18.2 (A), D27.2 (A), D36.2 (A), D45.2 (A), D54.2 (A), D63.2 (A), D72.2 (A), U1.21 (CA1)
/CA2: D9.2 (A), D10.2 (A), D11.1 (K), D12.1 (K), D13.1 (K), D14.1 (K), D15.1 (K), D16.1 (K), D17.1 (K), D18.1 (K), D26.2 (A), D35.2 (A), D44.2 (A), D53.2 (A), D62.2 (A), D71.2 (A), U1.22 (CA2)
/CA3: D8.2 (A), D17.2 (A), D19.2 (A), D20.1 (K), D21.1 (K), D22.1 (K), D23.1 (K), D24.1 (K), D25.1 (K), D26.1 (K), D27.1 (K), D34.2 (A), D43.2 (A), D52.2 (A), D61.2 (A), D70.2 (A), U1.23 (CA3)
/CA4: D7.2 (A), D16.2 (A), D25.2 (A), D28.2 (A), D29.1 (K), D30.1 (K), D31.1 (K), D32.1 (K), D33.1 (K), D34.1 (K), D35.1 (K), D36.1 (K), D42.2 (A), D51.2 (A), D60.2 (A), D69.2 (A), U1.24 (CA4)
/CA5: D6.2 (A), D15.2 (A), D24.2 (A), D33.2 (A), D37.2 (A), D38.1 (K), D39.1 (K), D40.1 (K), D41.1 (K), D42.1 (K), D43.1 (K), D44.1 (K), D45.1 (K), D50.2 (A), D59.2 (A), D68.2 (A), U1.25 (CA5)
/CA6: D5.2 (A), D14.2 (A), D23.2 (A), D32.2 (A), D41.2 (A), D46.2 (A), D47.1 (K), D48.1 (K), D49.1 (K), D50.1 (K), D51.1 (K), D52.1 (K), D53.1 (K), D54.1 (K), D58.2 (A), D67.2 (A), U1.26 (CA6)
/CA7: D4.2 (A), D13.2 (A), D22.2 (A), D31.2 (A), D40.2 (A), D49.2 (A), D55.2 (A), D56.1 (K), D57.1 (K), D58.1 (K), D59.1 (K), D60.1 (K), D61.1 (K), D62.1 (K), D63.1 (K), D66.2 (A), U1.27 (CA7)
/CA8: D3.2 (A), D12.2 (A), D21.2 (A), D30.2 (A), D39.2 (A), D48.2 (A), D57.2 (A), D64.2 (A), D65.1 (K), D66.1 (K), D67.1 (K), D68.1 (K), D69.1 (K), D70.1 (K), D71.1 (K), D72.1 (K), U1.28 (CA8)
/CA9: D1.1 (K), D2.2 (A), D10.1 (K), D11.2 (A), D19.1 (K), D20.2 (A), D28.1 (K), D29.2 (A), D37.1 (K), D38.2 (A), D46.1 (K), D47.2 (A), D55.1 (K), D56.2 (A), D64.1 (K), D65.2 (A), U1.1 (CA9)
/CH1_V: C2.1, C3.1, J1.7, J4.1, R1.2, SW1.2, U1.2 (VCC)
/CH1_VOUT: J2.7, J4.2
/CH2_V: J1.5, J4.3
/CH2_VOUT: J2.5, J4.4
/CH3_V: J1.3, J4.5
/CH3_VOUT: J2.3, J4.6
/CH4_V: J1.1, J4.7
/CH4_VOUT: J2.1, J4.8
/SCL: J3.2, U1.20 (SCL)
/SDA: J3.1, U1.19 (SDA)
/WAKE: J3.3, SW1.1
GND: C1.2, C2.2, C3.2, J1.2, J1.4, J1.6, J1.8, J2.2, J2.4, J2.6, J2.8, J3.4, R2.2, U1.5 (GND), U1.17 (IN), U1.18 (AD)
unnamed: C1.1, U1.16 (C_FILT)
unnamed: R2.1, U1.6 (R_EXT)
unnamed: R1.1, U1.3 (~SDB)

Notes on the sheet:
BAT 1
8X9 CHARLIEPLEXED LED MATRIX
BAT 4
LED MATRIX
LED DRIVER
BAT 2
PULL PINS
ACTIVATE
POWER OUT
POWER IN
DATA
DUAL 8X9 CHARLIEPLEXED LED MATRIX DRIVER
BAT 3

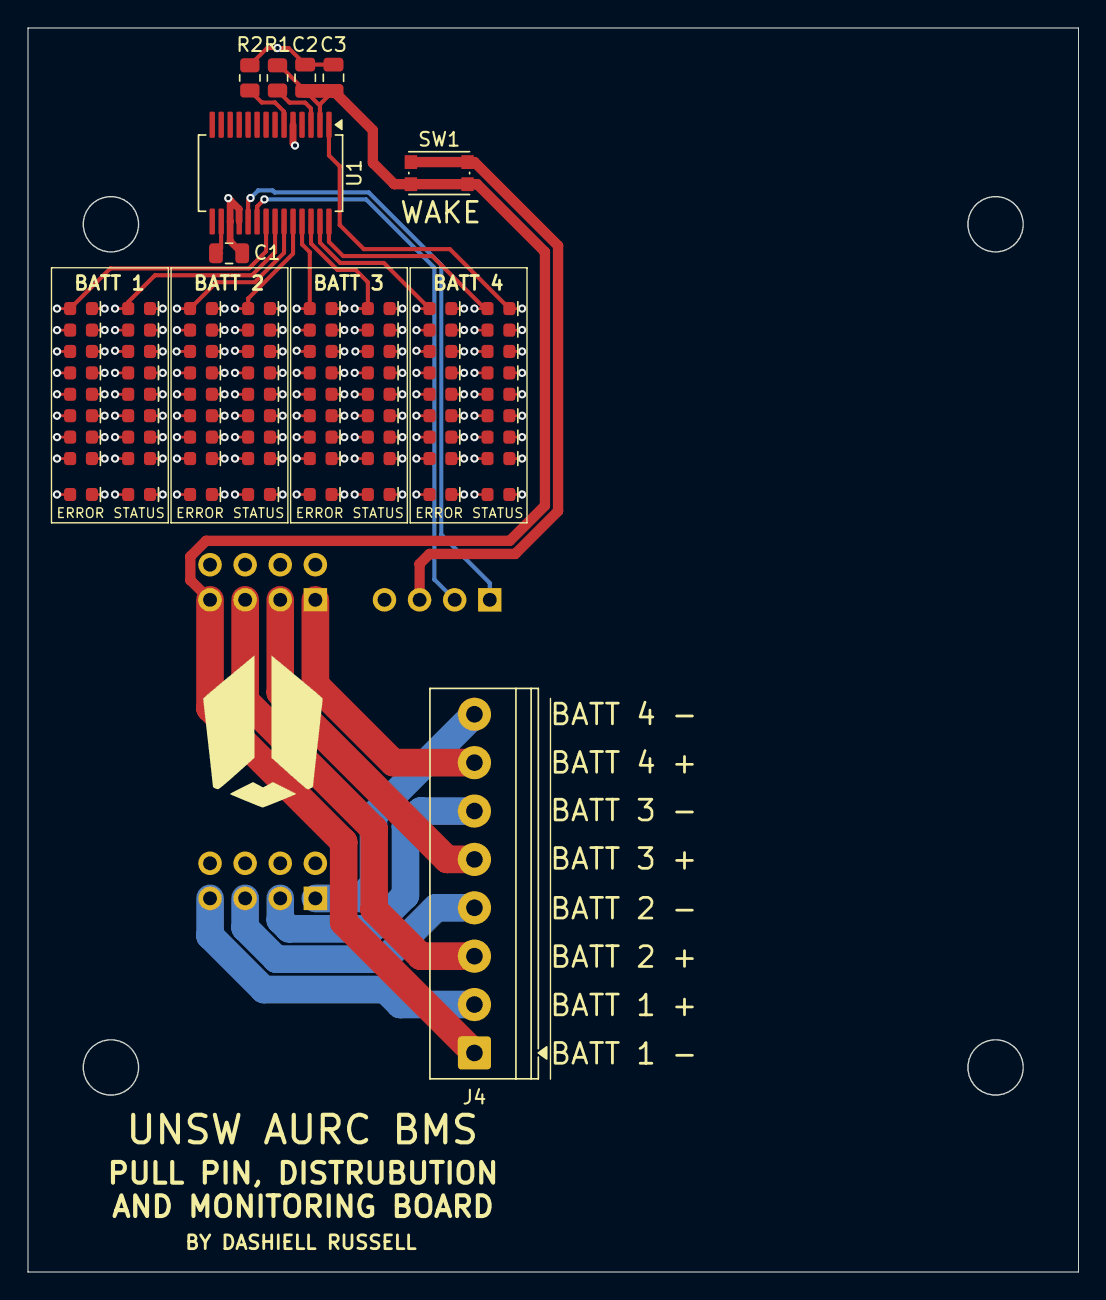
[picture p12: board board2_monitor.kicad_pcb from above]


Board: 4 copper layers, 76.0 x 90.0 mm, 83 parts (3 on the bottom side), 24 nets.

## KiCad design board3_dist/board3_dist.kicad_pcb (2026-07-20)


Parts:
J1: Conn_02x04_Odd_Even; PinSocket_2x04_P2.54mm_Horizontal
J2, J3, J4, J5: Screw_Terminal_01x02; TerminalBlock_Phoenix_PT-1,5-2-3.5-H_1x02_P3.50mm_Horizontal
J6, J7, J8, J9: Conn_01x02; PinSocket_1x02_P2.54mm_Horizontal

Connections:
/CH1_V: J1.2, J4.1
/CH2_V: J1.4, J5.1
/CH3_V: J1.6, J2.1
/CH4_V: J1.8, J3.1
/FC1_FCMP: J4.2, J7.2
/FC1_PYRO: J5.2, J6.2
/FC2_FCMP: J3.2, J8.2
/FC2_PRYO: J2.2
/FC2_PYRO: J9.2
GND: J1.1, J1.3, J1.5, J1.7, J6.1, J7.1, J8.1, J9.1

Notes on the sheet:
FC POWER CONECTORS
PULL PIN SCREW TERMINALS
BATTERIES


Board: 2 copper layers, 100.0 x 100.0 mm, 9 parts (0 on the bottom side), 8 nets.

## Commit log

2026-06-08 Restructure into three-board layout; sync docs; Board 1 capture plan
    - Split single-board project into board1_power / board2_monitor / board3_dist,
    each an independent KiCad project sharing libs/ (single source of truth).
    - Rename library to BMS.kicad_sym / BMS.pretty / 3dmodels; fix all refs.
    - Archive the old single-board project under _archive/single-board-v0.1/.
    - docs/architecture.md bumped to v0.3: SY6970 smart charger replaces
    MP2617 + MAX17048 (integrated I2C monitoring; fuel gauge dropped),
    ESP32-S3 confirmed, per-cell addressable RGB status LEDs added (§9b).
    - docs/interconnect.md: connector contract (J1/J1s/J2/J3, star ground).
    - docs/board1_power_capture_plan.md: full Boar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
    [AURC_BMS.kicad_pcb, AURC_BMS.kicad_sch, USB_IN.kicad_sch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]
2026-06-08 board1_power: migrate drawn capture (USB_IN + 4x charge channel)
    - Bring USB_IN and charge_chanel sheets forward from the archived single-board
    design into the live board1_power project; archive copy stays frozen.
    - Fix library references: lib_id and footprint nicknames AURC_BMS:/easyeda2kicad:
    -> BMS:; project-name strings -> board1_power; register sheet hierarchy in
    board1_power.kicad_pro.
    - Validated with kicad-cli sch erc: hierarchy loads, all BMS: symbols + footprints
    resolve. Remaining 169 violations are work-in-progress (unconnected pins, missing
    PWR_FLAGs, Unspecified pin-type warnings from imported symbols) — pre-existing
    capture state, not migration defects.
    - Capture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
    [USB_IN.kicad_sch, board1_power.kicad_sch, charge_chanel.kicad_sch]
2026-06-08 docs: lock in SYS-default rail with 0R SYS/LOAD select + protection rework
    - Channel CHn_V output is 0R-selectable: SYS (power-path, default) vs LOAD_P
    (direct battery); single PTC relocated after the selector fuses either.
    - Reverse-polarity P-FET moved to the cell terminal (always-on, guards the
    charger; Rds drop compensated via I2C VREG). Old Q2/Q3 LOAD-branch FETs
    dropped; keyed holder = primary reverse defense.
    - SY6970 datasheet-verified: VSYSMIN 3.5V, BATFET 10mohm / 9A OCP, 104% OVP,
    supplement mode. Bootstrap cap 47uF->47nF, PMID->6.8uF.
    - Added "no ship-mode in flight" reliability rule. architecture.md -> v0.4.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
2026-06-08 board1_power: SYS-default channel rework + ESP32-S3 + mux + connectors
    Channel (charge_chanel.kicad_sch):
    - Reverse-polarity P-FET (DMG2305UX) moved to cell terminal, drain-to-battery;
    charger BAT on CELL_P_PROT, DW01A sense stays on raw CELL_P.
    - 0R source selector (R_SYS populated / R_LOAD DNP, both 2010) -> CHn_V_pre,
    PTC relocated after it -> CH_V output. Old Q2/Q3 reverse FETs removed.
    - Bootstrap cap 47nF, PMID 6.8uF. Per-cell SK6812 RGB on LED_VDD=CH1_V chain.
    Root (board1_power.kicad_sch):
    - ESP32-C3 -> ESP32-S3-WROOM-1. SDA=IO8, SCL=IO9, MUX_RST=IO10(+TCA9548A RESET),
    RGB_DATA=IO48 via 330R, USB=IO19/20, boot IO0=pull-up+JP1, heartbeat=IO2.
    - Fixed IO45 strapping pin (was tie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
    [USB_IN.kicad_sch, board1_power.kicad_sch, charge_chanel.kicad_sch]
2026-06-08 board1_power: enable network corrected + all footprints assigned (schematic complete)
    - ESP enable rebuilt as a proper diode-OR + shunt:
    * MMBD4448HCQW (D12) quad common-cathode diode-OR -> EN, sources =
    {VBUS divider, CH1_V always-on strap (R59 now 100k), WAKE via 10k, self-hold}
    * R60 100k pull-down on EN (default off)
    * Q9 (2N7002) shunt: Drain->EN, Source->GND, Gate->off-header J4 (CH1_V when in)
    * off-header in -> ESP off (storage); out -> ESP on (launch)
    - Assigned footprints to the remaining 26 parts (R/C -> 0603, D1 LED, J2 signal
    connector placeholder); channel-sheet parts apply across all 4 instances.
    Remaining ERC items are benign/intentional (Unspecified-pin warnin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
    [USB_IN.kicad_sch, board1_power.kicad_sch, charge_chanel.kicad_sch]
2026-06-08 docs: sync architecture.md + interconnect.md to as-built Board 1
    - §7 ESP gate rewritten to the as-built diode-OR (MMBD4448HCQW) of
    {USB-divider, CH1_V always-on strap, WAKE, self-hold} -> AP2112K EN,
    100k pull-down, 2N7002 off-header shunt (RBF jumper in=off / out=on).
    Notes this supersedes the TPS22917 load-switch plan.
    - §9b: LED VDD is on CH1_V (ungated) + dormancy caveat.
    - §14: v0.5 "Board 1 schematic complete" entry.
    - interconnect.md: J1s pin 3 CH_LIVE -> WAKE; Board-2 gauge powered from
    CH1_V via the 8-pin power connector (no 3V3 pass-through); §13.2 resolved.
2026-06-08 board2_monitor: gauge matrix + IS31FL3731 driver + CA net-class colors (WIP)
    - 72-LED charlieplex matrix wired across CA1-CA9 (Matrix A), all valid.
    - IS31FL3731 (U1) gauge driver: VCC<-CH1_V, GND, SDA/SCL, AD->GND (0x74),
    IN->GND, CA1-CA9 -> matrix; CB1-CB9/INTB no-connected (Matrix B unused).
    - Added 9 net-class colors for CA1-CA9 (readable palette) + patterns.
    - Connectors J1s (SDA/SCL/WAKE/SGND) and power connectors in place.
    WIP: SDB pull-up (R1 10k) and R_EXT (R2 20k) free ends still need to land on
    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
    [board2_monitor.kicad_sch]
2026-06-19 libs: update BMS symbol lib + add BH-18650-A1BJ024 holder footprint
2026-06-19 board1_power: PCB footprint placement + layout updates
    [board1_power.kicad_pcb, board1_power.kicad_sch, charge_chanel.kicad_sch]
2026-06-19 board2_monitor: gauge matrix layout + LED designators corrected (column-major, 9 per column)
    [board2_monitor.kicad_pcb, board2_monitor.kicad_sch]
2026-06-19 libs: add UNSW Rocketry library (logos) + link in all boards
2026-06-19 board1_power: place UNSW Rocketry logo (large)
    [board1_power.kicad_pcb]
2026-06-19 board2_monitor: place UNSW Rocketry logo (small)
    [board2_monitor.kicad_pcb]
2026-06-20 board3_dist: connector schematic capture (J1-J9) + initial footprint placement
    [board3_dist.kicad_pcb, board3_dist.kicad_sch]
2026-07-17 connector fixes to the boards - swapped headers with sockets and vice versa. had to adjust the schematics too but no big changes, everything still connected appropriately
    [board1_power.kicad_pcb, board1_power.kicad_sch, board2_monitor.kicad_pcb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]
2026-07-20 board2_monitor: routing updates (+25 segments)
    [board2_monitor.kicad_pcb]
2026-07-20 board4_nosecone: 2-cell nosecone BMS design docs + reused sheets
    Single-board 2-channel (FC/logic only, no pyro) derivative of the
    board1-3 set. Key deltas: no TCA9548A (one SY6970 per ESP32-S3 I2C
    controller), 2x SK6812 status RGBs (no IS31FL3731 gauge), on-board WAKE
    tact switch, 1x4 screw terminal for both pull-pin loops, 9V PD default,
    N-prefixed nets. Architecture doc is delta-style vs architecture.md v0.5.
    Copied board1's proven charge_chanel + USB_IN sheets in for reuse.
    [USB_IN.kicad_sch, board4_nosecone.kicad_pcb, board4_nosecone.kicad_sch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]
2026-07-20 board4_nosecone: complete schematic (ESP, cells, CFG 9V, dual holder)
    - ESP32-S3 block wired: dual I2C buses (no mux), diode-OR gate, USB
    programming, RGB chain, WAKE/BOOT/RESET buttons
    - CH224K strapped to 9V (CFG1/2/3 all to GND)
    - BH-18650-B6AA007 dual 18650 holder: symbol added to BMS lib (5-pin,
    C1+/C1-/C2+/C2-/hidden mechanical), footprint relocated to BMS.pretty
    and renamed from misfiled UNSW_ROCKETRY_LIBRARY:BMSBH-18650-B6AA007
    - BT1 placed, wired to CELL1/CELL2 nets
    docs/board1_fixes_todo.md: main-board bugs found during the copy -
    CFG2/CFG3 floating (PD not deterministically 12V), heartbeat LED
    missing series resistor.
    Known WIP: heartbeat LED (D1) on board4 still needs ser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
    [USB_IN.kicad_sch, board4_nosecone.kicad_pcb, board4_nosecone.kicad_sch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]
2026-07-21 board1_power: fix PD straps + heartbeat LED resistor
    - CH224K now deterministically 12V: CFG1->GND (0R), CFG2->GND (0R),
    CFG3->VDD_PD (10k pull-up = logic 1). Previously CFG2/CFG3 floated.
    - Heartbeat LED D1 now has 330R series resistor to IO2 (was direct
    GPIO->LED->GND).
    Closes the two items in docs/board1_fixes_todo.md.
    [USB_IN.kicad_sch, board1_power.kicad_pcb, board1_power.kicad_sch]
2026-07-21 board4_nosecone: routing progress (+70 segments, +31 vias)
    [board4_nosecone.kicad_pcb]
